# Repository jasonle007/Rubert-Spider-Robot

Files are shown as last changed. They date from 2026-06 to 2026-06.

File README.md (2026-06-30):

# Rubert — Jansen Linkage Spider Robot

*A build log of a walking spider robot. Lots of failed prints. Some things that actually worked.*



---

## What This Is

Rubert is a spider inspired walking robot I built as part of the WOOF3D bio inspired robotics project at UW. The goal was a Jansen linkage leg mechanism that actually walks: one servo per leg, two degrees of freedom per leg output, and a gait pattern that looks like something alive rather than something shuffling.

I named it Rubert because I like it and the main goal was to master the jansen linkage and get this thing walking, so that's what this is.

This repo documents the process: the CAD, the Python simulation I used to verify link geometry before printing, the print failures, and what finally worked. It's also a record of a project that's still going. The leg walks. The full robot gait is a work in progress.

---

## Context: The WOOF3D Project

This came out of the WOOF3D club's bio inspired robotics project, which split into sub teams across different problems: body and electronics, rotational/steering mechanisms, a jumping mechanism, PID stabilization, and remote control. I took on the Jansen linkage leg specifically.

The broader robot concept is a jumping spider inspired platform, roughly 150x150x75mm, with 8 legs total: 6 for walking (2 DOF each), 2 rear legs reserved for jumping (potentially 3 DOF). The walking motion uses hexapod gait logic, keeping 4 legs on the ground at any given time. The jumping legs are a separate problem the team is still working through.

My piece was getting the Jansen linkage leg to a printable, working mechanism with one servo input. Everything else depended on that being solved first.

---

## Why Jansen Linkages

The decision came down to Jansen vs. Klann, which the team debated early on. Both are planar walking mechanisms that convert rotary input into a foot trajectory. The differences matter at this scale.

Klann linkages are simpler: fewer links, easier to assemble, and the geometry is more forgiving. Another team member went deep on Klann optimization and got 20% more stride length than baseline ratios. It's a solid mechanism.

Jansen linkages use 13 bars (with a crank arm and 12 links) and produce a foot path that more closely mimics natural walking: the foot lifts, travels forward, and plants flat with low ground clearance variation during the stance phase; however the tradeoff is complexity. The geometry has to be right and is based off of Theo Jansen's "holy numbers" that specify link length ratios for this motion.

I chose Jansen because the foot path was closer to what spider locomotion actually looks like, the motion was greatly sastifying, and because I wanted the harder problem.

The specific link lengths I used in simulation (scaled by 1.5x from Jansen's original ratios):

| Link | Jansen Ratio | Scaled (1.5x) |
|---|---|---|
| Crank (bar 1) | 1.5 | 2.25 |
| Bar 2 | 3.8 | 5.70 |
| Bar 3 | 4.15 | 6.225 |
| Bar 4 | 3.93 | 5.895 |
| Bar 5 | 4.01 | 6.015 |
| Bar 6 | 5.58 | 8.37 |
| Bar 7 | 3.94 | 5.91 |
| Bar 8 | 3.67 | 5.505 |
| Bar 9 | 6.57 | 9.855 |
| Bar 10 | 4.9 | 7.35 |
| Bar 11 | 5.0 | 7.5 |
| Bar 12 | 6.19 | 9.285 |
| Frame offset X | 3.8 | — |
| Frame offset Y | 0.78 | — |

---

## Simulation Before Printing

Before cutting any geometry into CAD, the team sourced a Python simulation of the single leg linkage to verify that the foot path looked right and that the joint positions were solving correctly.

The sim uses a circle intersection algorithm to resolve each joint position through one full crank rotation, iterating across 120 angular increments. Joint 1 (crank center) and Joint 2 (frame point) are fixed. Everything else, upper triangle, mid joint, lower triangle, knee joint, and foot is computed from the two fixed anchor points and the link lengths. The solver picks between the valid intersection solutions (high/low/left/right) at each joint to enforce the correct assembly configuration.

Running it before printing caught a couple of things:

- My initial scale factor was too small. The foot path was geometrically correct but the links were going to be thin enough that they'd break in bending.
- The frame offset values (frameX = 3.8, frameY = 0.78) needed to match the physical mounting geometry exactly, otherwise the sim and the physical assembly would diverge even if the link lengths were right.

The simulation source is in `/code/IsolatedJansenLinkage.py`. To run it with animation:

```bash
pip install numpy matplotlib
# In an IPython console, first run:
# %matplotlib qt
python IsolatedJansenLinkage.py
```

Set `moving = True` in the script to see the leg translate across the screen rather than animate in place.

---

## Hardware

**Electronics (from the team's parts list):**

| Part | Model | Cost |
|---|---|---|
| Micro Servo (x6) | MG90S | ~$25 total |
| Servo Driver | PCA9685 16-channel PWM | ~$6 |
| Microcontroller | Seeed XIAO ESP32C3 | ~$5 |
| Filament | colorFabb LW-PLA | ~$38 |

The LW-PLA was a deliberate choice being about 60% lighter than standard PLA because it foams during printing.

The PCA9685 servo driver handles PWM signal generation so the ESP32 isn't bottlenecked generating 6 servo signals simultaneously. The board communicates over I2C, which also leaves the ESP32 GPIO pins free for other things (sensors, future remote control, tilt feedback).

---

## CAD and Assembly

The SolidWorks model has 38 components. Most are link geometry, but the harder design work was in the joints.

Jansen linkages need joints that rotate freely without slop. At this scale, that means interference fit pegs and spacers rather than fasteners. My first pass at the joints had too much clearance and the links flopped. The second pass was too tight and the assembly bound up after a few cycles. By the third pass I had a working tolerance offset and kept a running log of designed vs. printed dimensions for every critical feature from that point forward.

One thing I hadn't thought through initially: the peg material matters as much as the diameter. I ended up printing pegs at higher infill than the link bodies. The peg compresses slightly on insertion, seats firmly, and holds rotation without binding. Link bodies at lower infill kept weight down without sacrificing enough strength to matter for the bending loads.

The body positions leg assemblies at specific phase offsets around a central shaft. Phase offsets in CAD are easy to set. Phase offsets in a physical assembly with tolerance stack across 38 parts are a different thing. The middle legs in particular ended up slightly off phase, which is still visible in the gait.

CAD Model:



---

## Printing

10+ prototype iterations. The things that actually caused failures:

**Layer defects from printing multiple parts simultaneously.** I was printing all the links for a single leg laid out flat on one build plate. The nozzle would do a pass across all parts, move to the next layer, and the previous layer cooled unevenly in the time between passes. This showed up as weak layer adhesion and occasional delamination under repeated load.

The fix was sequential printing: one part at a time, fully completed before moving to the next. Print time went up significantly, but the structural consistency was noticeably better.

**Link orientation and bending strength.** Jansen links are long, thin, and loaded in bending during the stance phase. Printing them flat (length along the bed) puts layer lines perpendicular to the bending stress axis, which is the weak direction for FDM. A few links snapped at layer boundaries during early testing. Printing them vertically with layer lines parallel to the long axis fixed the strength issue, at the cost of needing supports.

**Tolerancing.** Circular holes in my prints ran about 0.2mm undersized consistently, which is normal for FDM, but it varied by feature geometry. Slotted holes behaved differently than circular ones. Thin features on links warped slightly without adequate support contact. I added chamfers to most joint faces in later iterations, which made assembly easier and reduced the chance of binding during insertion.

6 Jansen Linkages Printed and Assembled:



---

## What Worked

By iteration 5 or so, the single leg was walking correctly. The foot traced a clean oval, lifted consistently, and didn't drag on the return stroke. The sequential printing made a real difference in joint quality.

The simulation was worth doing before printing. A few potential link collisions showed up in the CAD model that I might not have caught until the physical assembly. That saved at least two full print cycles. The SolidWorks collision detection in the motion study also helped check that adjacent links didn't interfere mid rotation.

However, CAD does not see everything and it took 3 more print iterations after that to resolve all colisions and interferences through adding slits in the legs and changing spacer width.

---

## What's Still Broken

**Middle leg phasing.** The front and rear leg pairs walk reasonably well. The middle legs are awkward. I think it's a combination of phase offset error accumulated during assembly and small geometric variation between printed legs. A more rigid central shaft would help, and tighter phase indexing at the mounting points.

**No steering.** With a fixed Jansen geometry and one continuous servo per leg, the robot walks in one direction. The team is working through a few steering approaches (rack and pinion, differential servo speed between sides), but none are implemented on Rubert yet.

**Thin feature consistency.** Features under about 3mm still come out with occasional layer adhesion issues even with sequential printing. Minimum feature thickness needs to go up, or I switch the link material for the next version.

**Full gait coordination.** A single leg walking correctly and eight legs walking together are different problems. The phasing gets set mechanically at assembly time, which means it's fixed. Getting it right across all eight legs in one assembly hasn't happened yet.

**Linkage buckle.** The linkages experience great amounts of friction with the ground and due to power issues and the servos not generating enough torque, too much weight can be placed on a leg causing the middle rectangular section to buckle inwards and collapse the linkage motion. The issue isn't permanent as the linkage can be popped out again, but this failure reveals a design flaw possibly in the linkage design it self or from the lack of structural intergrity from the 3D printed parts and spacings.

---

## What's Next

Per the team's current plan:
- Miniaturize the body, legs, and eventually the jumping mechanism
- PID control per leg, with a tilt sensor providing feedback to adjust all legs collectively
- Rotation/steering: still deciding between a rack-and-pinion mechanism and differential speed control
- Remote control via the ESP32's WiFi capability

On the Jansen side specifically: I want to rebuild the central shaft with tighter phase indexing before addressing the middle leg problem. If that doesn't fix it, the next step is going back to the simulation to check whether the phase angles I'm using are actually optimal for the gait pattern I'm targeting.

---

## Research Notes and References

Collected during the early research phase by the team:

**Linkage mechanisms:**
- [Jansen's Linkage — Wikipedia](https://en.wikipedia.org/wiki/Jansen%27s_linkage)
- [Klann Linkage — Wikipedia](https://en.wikipedia.org/wiki/Klann_linkage)
- [Analysis of Jansen and Klann Linkages — Springer](https://link.springer.com/article/10.1007/s11044-016-9532-9)
- [Walker Mechanism Thesis](http://boim.com/misc/WalkerMechanismThesis.pdf)
- [507 Mechanical Movements](https://507movements.com/)
- [Four-Bar Linkage Analysis and Synthesis — ResearchGate](https://www.researchgate.net/profile/L-Roy/publication/277584753_Analysis_and_Synthesis_of_Four_bar_Mechanism/links/55993c7a08ae21086d254047/Analysis-and-Synthesis-o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)

**Spider locomotion:**
- [Arachnid Locomotion — Wikipedia](https://en.wikipedia.org/wiki/Arachnid_locomotion)
- [Unsupervised learning reveals rapid gait transitions (Journal of Experimental Biology)](https://journals.biologists.com/jeb/article/228/12/jeb250243/368261/Unsupervised-learning-reveals-rapid-gait)
- [Jumping Spider Slow Motion](https://www.youtube.com/watch?v=FfOrLNXIN-8) — only the rear 4 legs power the jump; the front legs brace landing
- [How Jumping Spiders Jump (hydraulic mechanism)](https://www.youtube.com/watch?v=hMxq0WXdxVQ)
- [Biomimetic Spider Leg Joints — ResearchGate](https://www.researchgate.net/publication/305361550_Biomimetic_Spider_Leg_Joints_A_Review_from_Biomechanical_Research_to_Compliant_Robotic_Actuators/link/68149363ded4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)

**CAD and printing techniques explored:**
- Print in place hinges and joints
- Compliant joints for spring like behavior
- Bistable mechanisms for energy storage (jumping application)
- Sequential printing

**Inspiration projects:**
- [Crawl-E (Yudurobotics)](https://wiki.yudurobotics.com/index.php?title=Crawl-E)
- [Sesame Robot (GitHub)](https://github.com/dorianborian/sesame-robot)
- [3D Printed Biologically Inspired Robotics (Instructables)](https://www.instructables.com/3D-Printed-Biologically-Inspired-Robotics/)

---

## Files

```
/code
    IsolatedJansenLinkage.py    — Python simulation of single-leg foot path

/CAD
    /SolidWorks                 — 38-part assembly and individual part files
    /Onshape                    — Earlier iteration geometry exploration

/docs
    /tolerance-log              — Designed vs. printed dimensions across iterations
    /print-settings             — Per-part print orientation, infill, and support notes
    /research                   — Linkage analysis notes and locomotion references
```

---

## Tools

- SolidWorks (final CAD and motion study)
- Onshape (early iteration work)
- Python / matplotlib (linkage simulation)
- Arduino / ESP32 (servo control via PCA9685)
- FDM printer, PLA filament

---

## Status

Single leg: working.  
Full 6-leg gait: partially working, middle legs still off.  
Steering: not implemented.  
Jumping: team is still on it.

Updates will come as the build continues next academic year.

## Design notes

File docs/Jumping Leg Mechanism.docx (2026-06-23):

- Jumping spiders use a semi hydraulic system in their bodies to jump.
  - Build up of pressure in their cephalothorax which forces fluid into their legs
  - Muscles only used to bend or flex legs, not responsible for the power in jump
  - (also usually attach a silk dragline behind them as a safety tether
    - Could be cool to incorporate

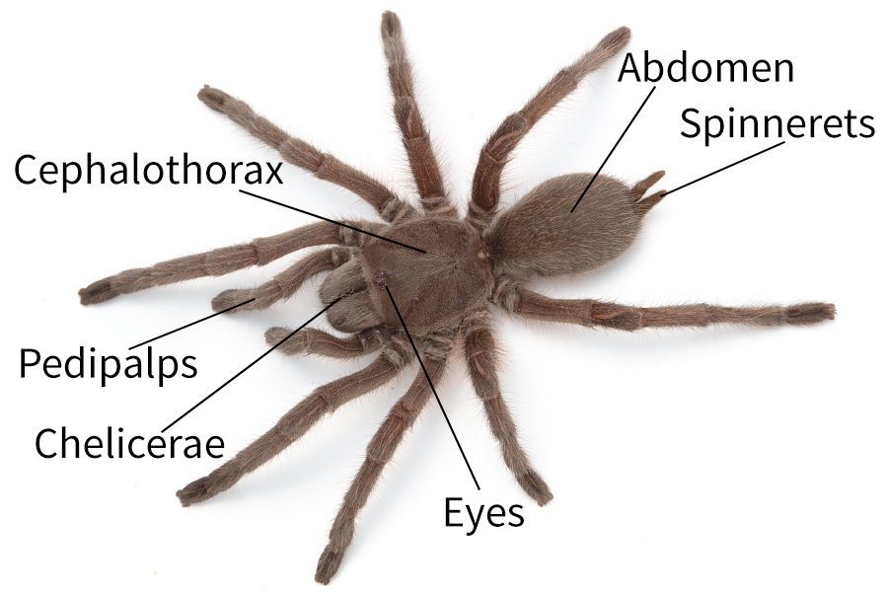
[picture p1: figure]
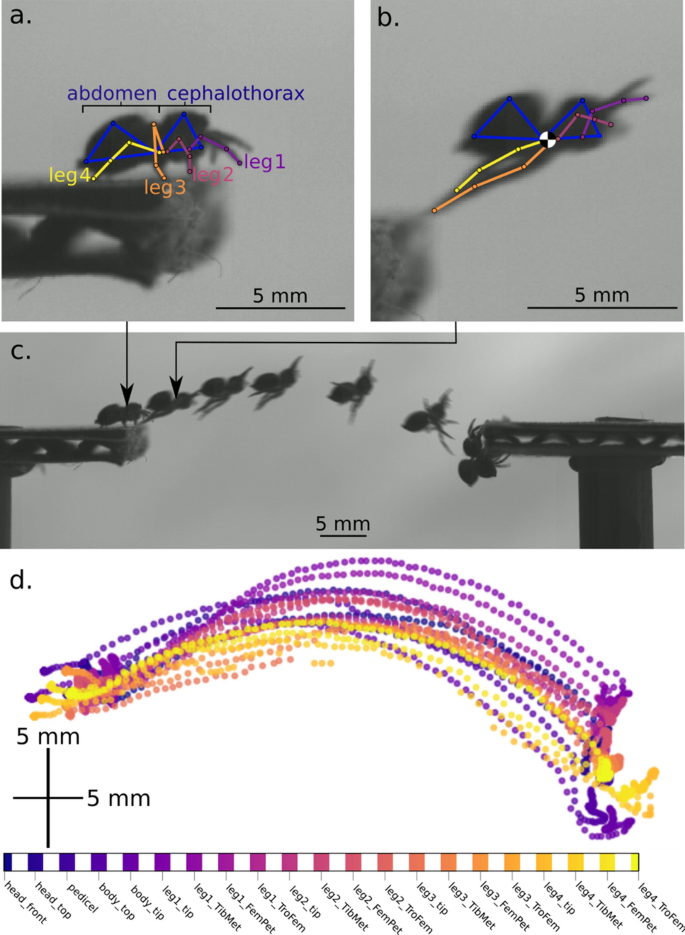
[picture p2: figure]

- spiders reached a peak speed of 0.62 ± 0.16 m/s
- Spiders achieved kinetic energies of 2.27 ± 1.23 µJ
- drag forces on spiders were 2.60 × 10–3 ± 2.33 × 10^-3 mN
- Optimal launch angle to cover max distance with air resistance accounted: 30-40 degrees
- Spiders cna usually jump about 6 times their body weight
  - If surfaces are equal height
- https://www.youtube.com/watch?v=xfP-7sbfiWk&t=133s
  - Video on design for hydraulic membrane mechanism for leg

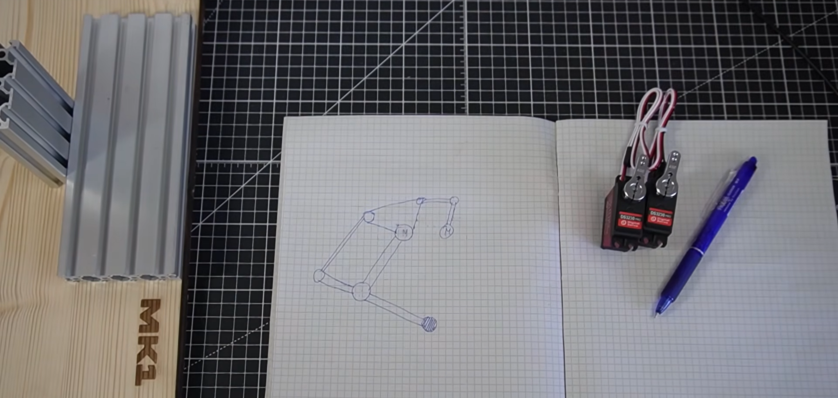
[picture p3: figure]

- https://www.youtube.com/watch?v=6z5tpfBbgLo

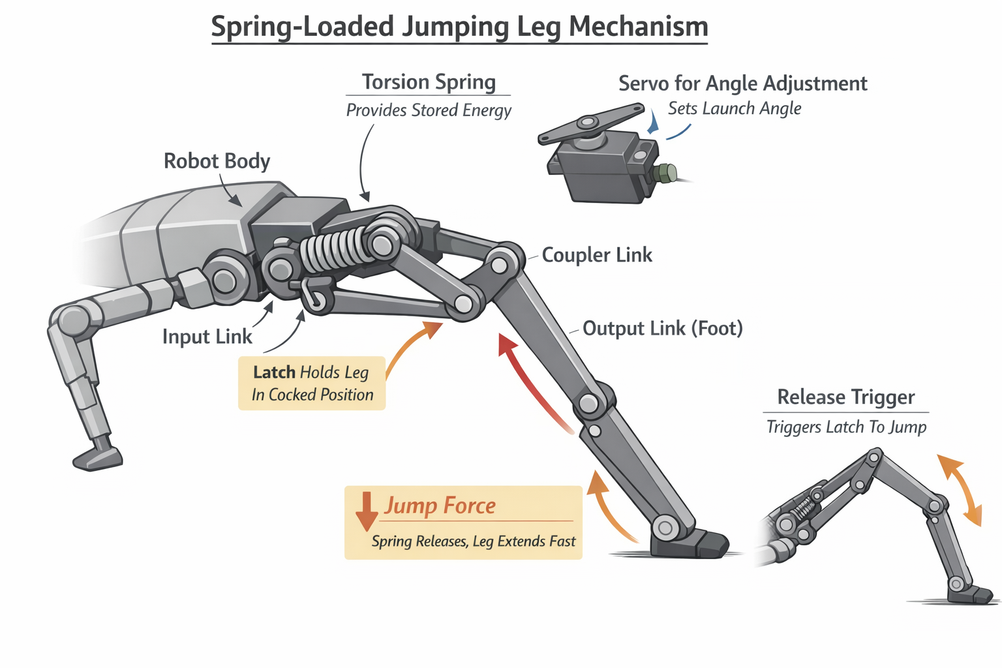
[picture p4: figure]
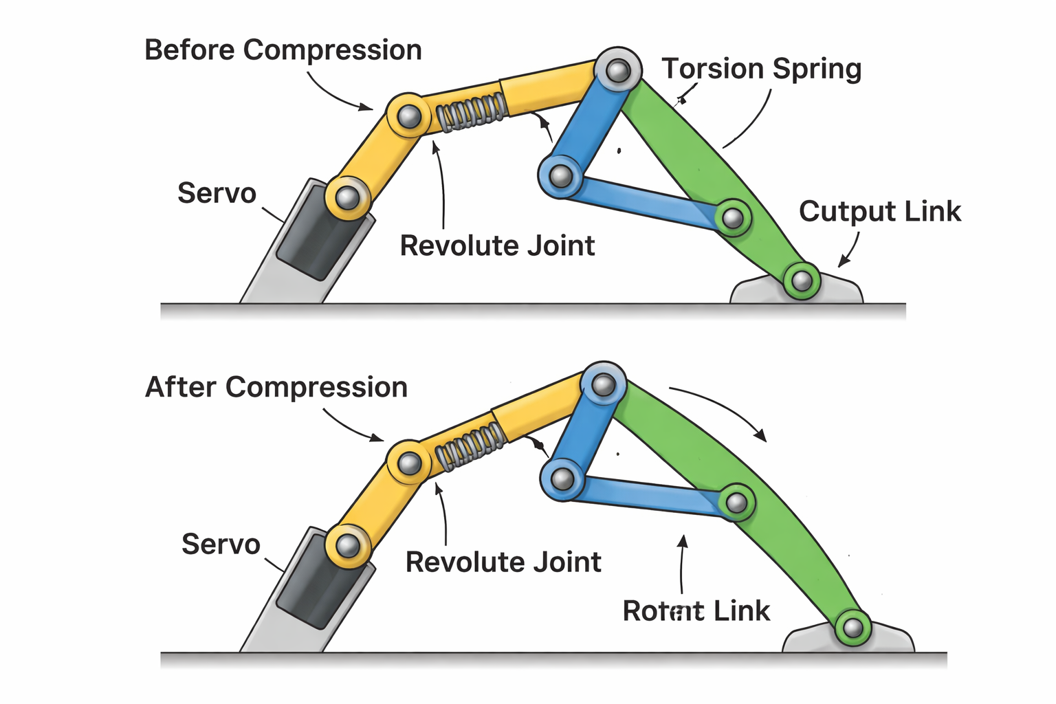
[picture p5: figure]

https://www.youtube.com/watch?v=SlGsq0yKnsk

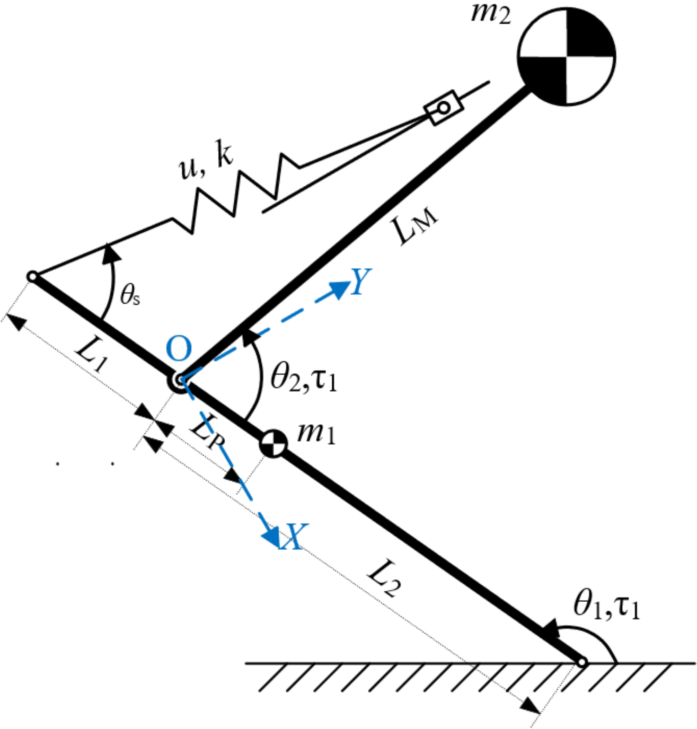
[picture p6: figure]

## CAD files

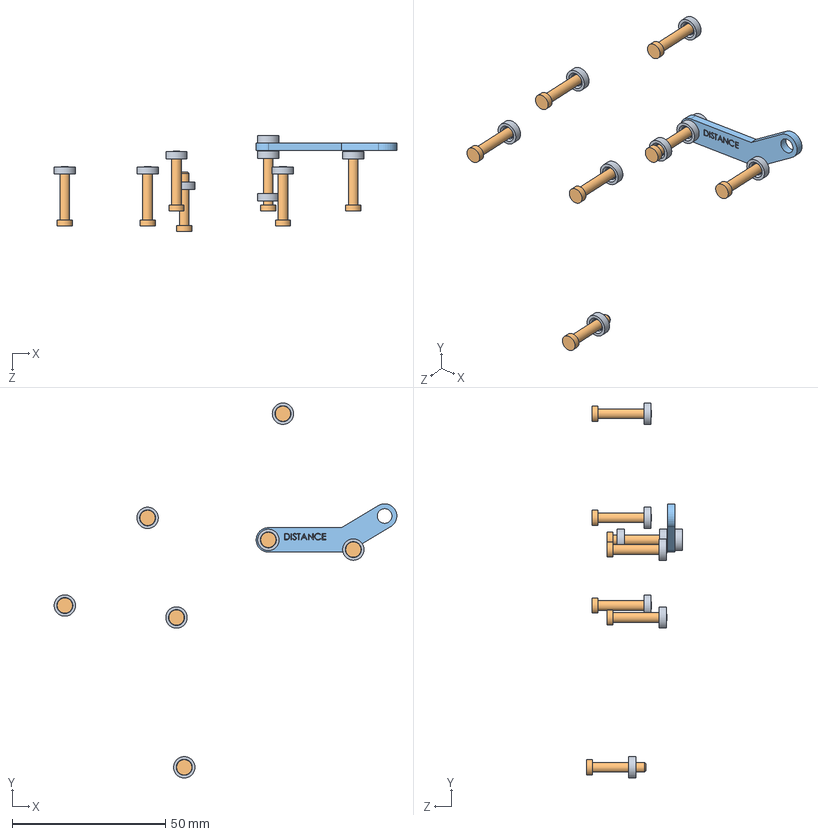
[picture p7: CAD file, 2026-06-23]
CAD/JansenLinkageV2/Jansen_SubAssemblyRIGHT.SLDASM
112.0 x 122.5 x 31.4 mm
Distance_Bar
PegConnectors x 7
Linkage_Spacer x 9

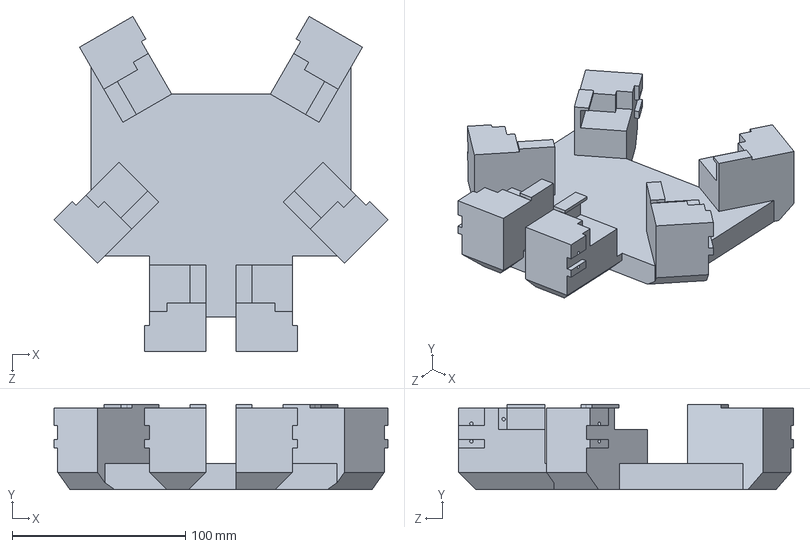
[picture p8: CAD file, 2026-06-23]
CAD/Body Assembly/Spider_Body.SLDPRT
192.6 x 49.2 x 193.3 mm

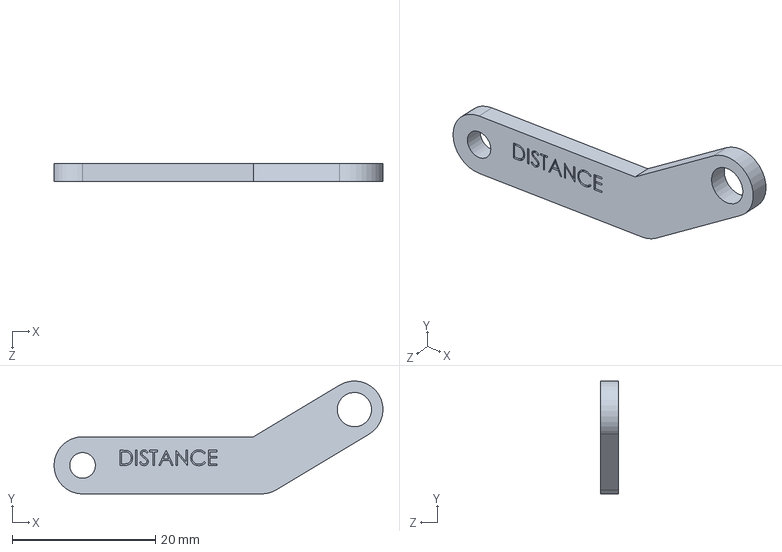
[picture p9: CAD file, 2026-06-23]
CAD/JansenLinkageV2/Distance_Bar.SLDPRT
46.0 x 15.8 x 2.50 mm

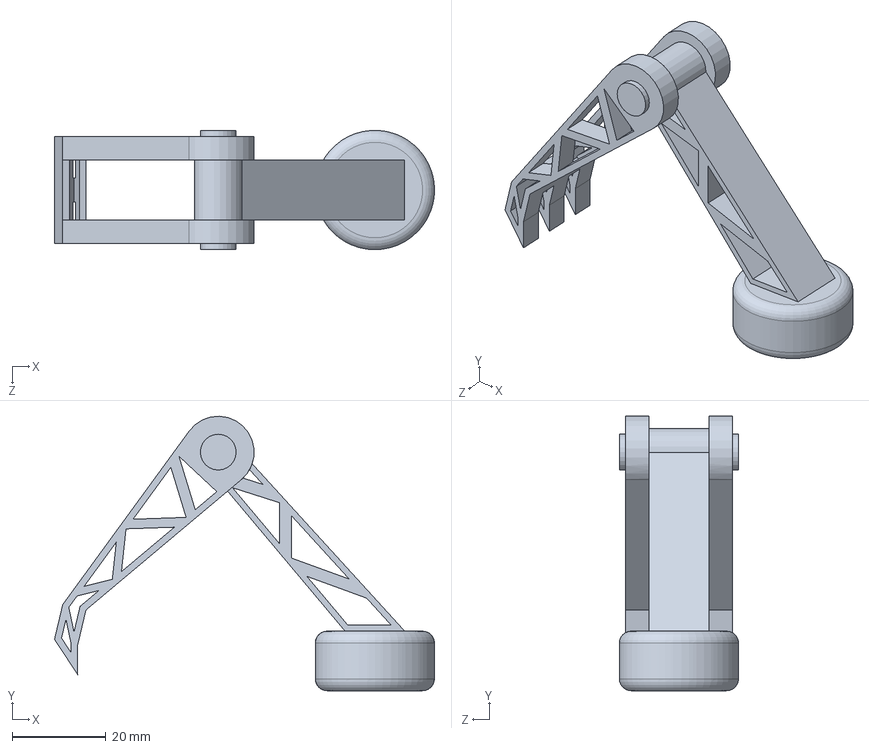
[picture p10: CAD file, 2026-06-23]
CAD/Body Assembly/Spider_Leg_Mock_V1.SLDPRT
80.9 x 58.4 x 25.4 mm

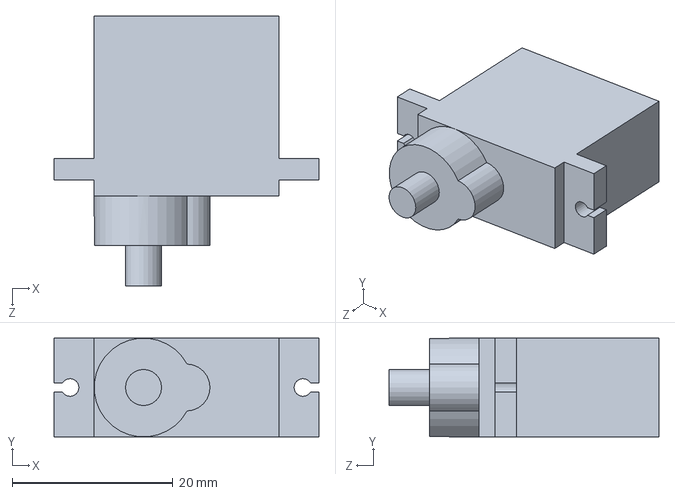
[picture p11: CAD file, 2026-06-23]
CAD/Body Assembly/Servo_Model.SLDPRT
33.0 x 12.3 x 33.6 mm

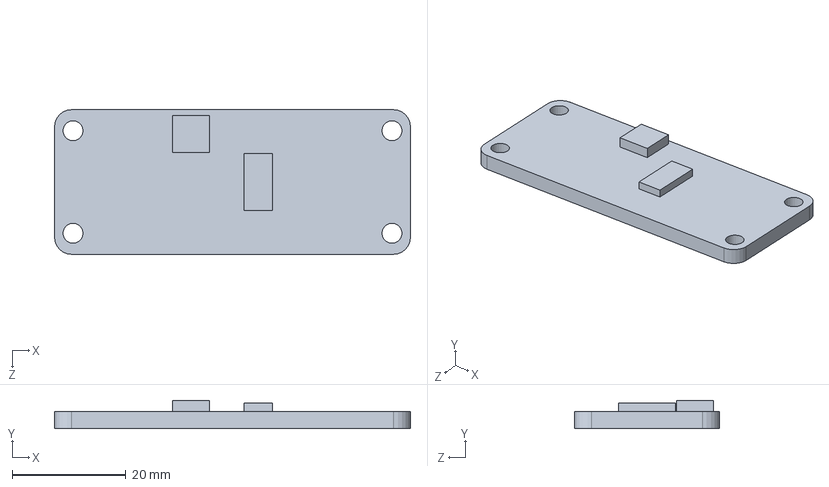
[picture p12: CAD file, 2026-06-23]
CAD/Body Assembly/pca9685 servo driver.SLDPRT
62.5 x 5.00 x 25.4 mm

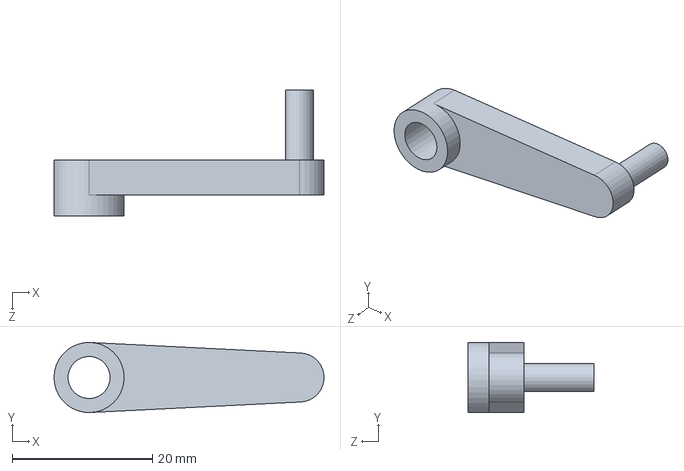
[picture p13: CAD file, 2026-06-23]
CAD/JansenLinkageV2/Crank_Arm.SLDPRT
38.5 x 10.0 x 18.0 mm

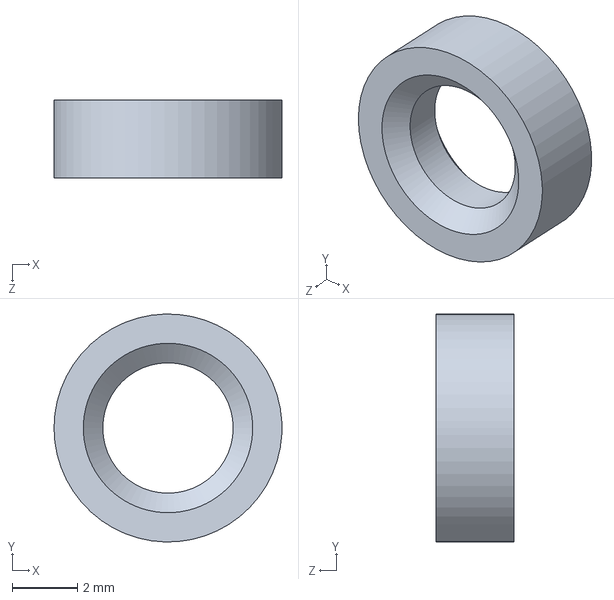
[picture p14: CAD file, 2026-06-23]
CAD/JansenLinkageV2/Linkage_Spacer.SLDPRT
7.00 x 7.00 x 2.40 mm

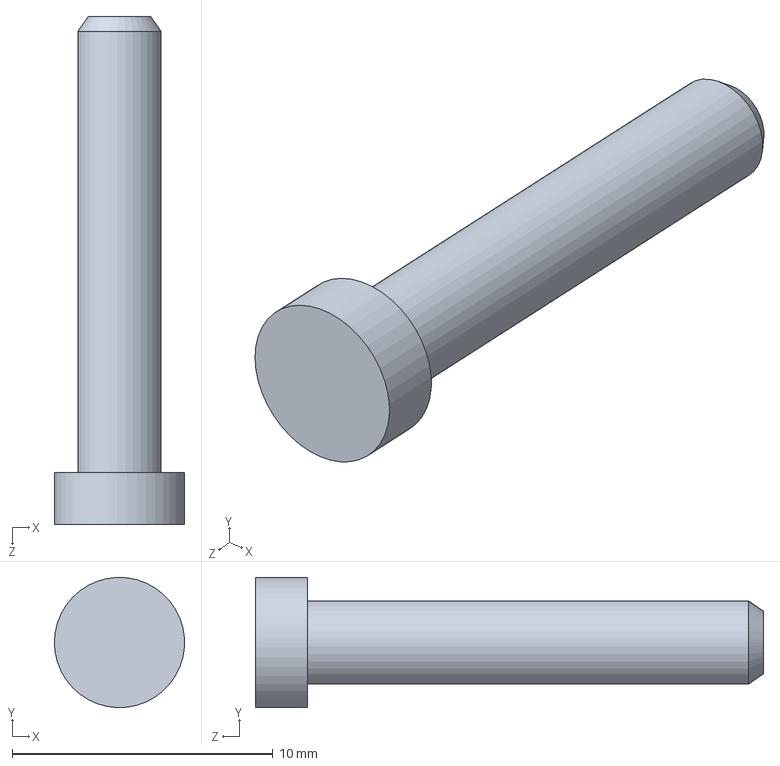
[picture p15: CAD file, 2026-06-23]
CAD/JansenLinkageV2/PegConnectors.SLDPRT
5.00 x 5.00 x 19.5 mm

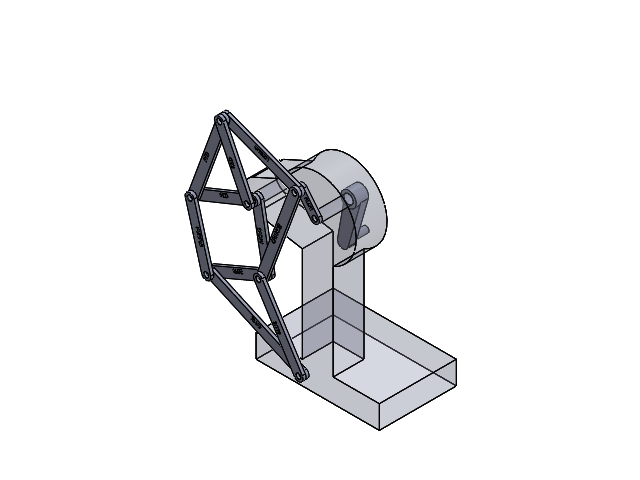
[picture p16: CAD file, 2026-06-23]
CAD/JansenLinkageV2/Jansen_Linkage_Demo.SLDASM
Crank-Tower
Crank_Arm
Jansen Leg x 11

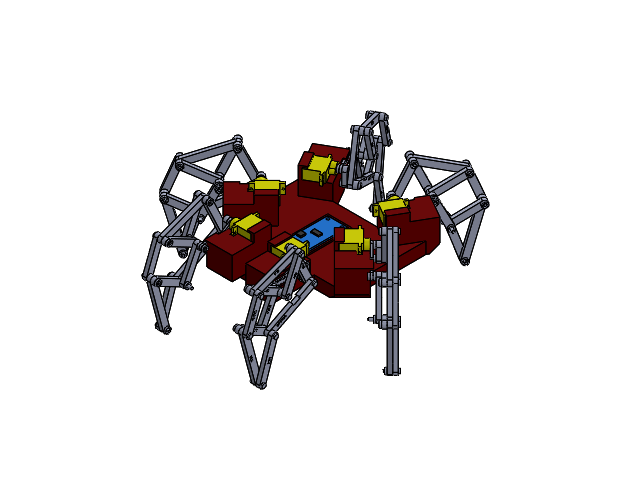
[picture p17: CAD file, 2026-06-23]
CAD/Body Assembly/Spider_Assembly.SLDASM
Spider_Body
Servo_Model x 6
Distance_Bar x 3
Jansen Leg x 33
PegConnectors x 21
Linkage_Spacer x 27
pca9685 servo driver
MirrorDistance_Bar x 3
MirrorJansen Leg x 33
MirrorPegConnectors x 21
MirrorLinkage_Spacer x 27

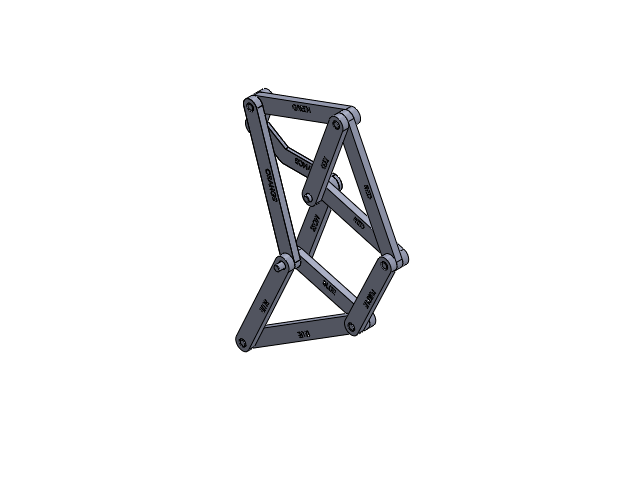
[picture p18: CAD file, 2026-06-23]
CAD/JansenLinkageV2/Jansen_SubAssemblyLEFT.SLDASM
Distance_Bar
Jansen Leg x 11
PegConnectors x 7

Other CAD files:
CAD/JansenLinkageV2/MirrorJansen_SubAssemblyRIGHT2.SLDASM
CAD/JansenLinkageV2/MirrorJansen_SubAssemblyRIGHT1.SLDASM
CAD/JansenLinkageV2/MirrorJansen_SubAssemblyRIGHT.SLDASM
CAD/JansenLinkageV2/MirrorDistance_Bar.SLDPRT
CAD/JansenLinkageV2/MirrorLinkage_Spacer.SLDPRT
CAD/Body Assembly/Servo.sldprt
CAD/JansenLinkageV2/Crank-Tower.SLDPRT
CAD/JansenLinkageV2/Jansen Leg.SLDPRT
CAD/JansenLinkageV2/MirrorJansen Leg.SLDPRT
CAD/JansenLinkageV2/MirrorPegConnectors.SLDPRT

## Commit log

2026-06-23 Added CAD Files
    [Crank-Tower.SLDPRT, Crank_Arm.SLDPRT, Distance_Bar.SLDPRT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]
2026-06-23 Added CAD Directory
    [Crank-Tower.SLDPRT, Crank_Arm.SLDPRT, Distance_Bar.SLDPRT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]
2026-06-23 Added jumping leg mechanism research file.
